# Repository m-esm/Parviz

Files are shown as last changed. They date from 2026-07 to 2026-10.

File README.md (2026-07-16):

<p align="center">
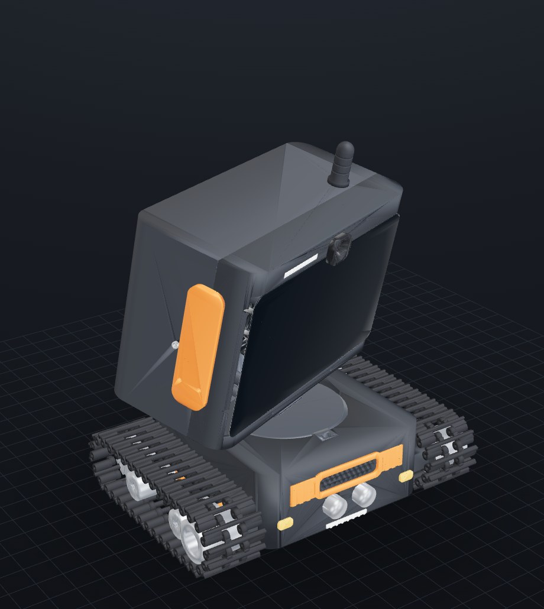
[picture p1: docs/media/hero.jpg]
Parviz, a 3D-printed tracked desk robot
  
</p>

<h1 align="center">Parviz</h1>

<p align="center"><b>Your desk AI.</b> A 3D-printed tank-tracked robot with a real face.</p>

<p align="center">
  <a href="https://m-esm.github.io/Parviz/viewer_glb.html"><b>&#9654; Spin the full assembly in your browser</b></a>
  &mdash; live 3D viewer with pan/tilt pose sliders, per-part toggles and the fit map
</p>

Parviz is a small tank-tracked robot that lives on a desk. A Raspberry Pi 5 drives
the official 7" touchscreen as an animated face, a Camera Module 3 sits behind the
forehead as an eye, and a pan/tilt neck lets the head look around. Two motor-driven
tank tracks let it drive. The whole thing is designed to print on a hobby FDM machine
(Bambu A1 class) and assemble with M2/M3 hardware plus a handful of bought bearings.

The mechanical design is parametric Python (`trimesh` + `manifold3d` + `shapely`), built
into a single `web/assembly.glb` you can spin in a browser. Every geometry change goes
through a headless render-and-inspect loop and a pairwise + pose-grid interference gate
before it counts as done. 39 parts, of which 10 are watertight printed structural parts;
the rest are cosmetics, bought hardware, and mechanism placeholders.

**Status:** design-complete and interference-gated in CAD, not yet printed or assembled.

## Designed to a concept, not vibes

<p align="center">
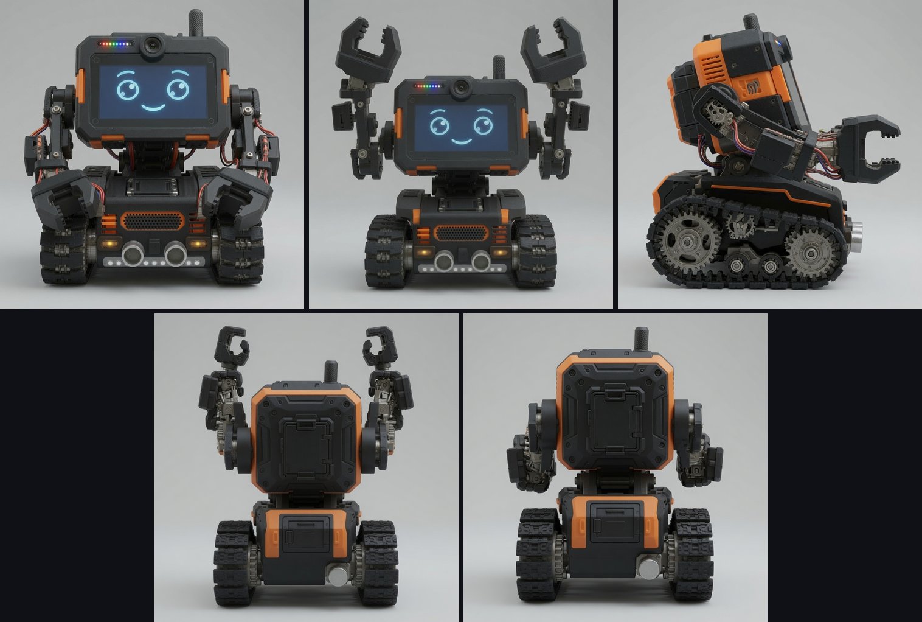
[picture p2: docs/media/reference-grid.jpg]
The five AI concept renders that define Parviz's look
  
</p>

The look came first. Five concept renders (`reference/design/`) fixed the design language:
a black-and-orange tracked body, a clean rounded tablet head with a cyan-eyed face, corner
lamps, a stubby antenna. The CAD was then built to match that silhouette around the real
hardware, not the other way round. The head is a rounded box (it started as an Echo-Show
wedge, since simplified) sized 205 mm wide to wrap the actual 192.96 mm touchscreen+Pi
module with room for the bezel.

## How it's engineered

**Tilt = self-locking worm drive.** The head pitches on a single-start involute worm meshing
a 12-tooth helical wheel, module 1.25, center distance 11.9 mm, lead angle ~8.1°. Single-start
plus printed-PLA friction (µ ≈ 0.3 vs the 0.129 self-lock threshold) means the head holds any
tilt angle with the motor de-energized: no idle current, no heat. The worm rides a 28BYJ-48
stepper (shaft +Y, right-angle to the axle); the wheel keys to a Ø5 hollow axle turning in two
695-2RS bearings pressed into the neck cheeks. Real tooth geometry is generated from first
principles (numpy involute → manifold twisted extrude) and verified to mesh cleanly (zero boolean interference)
at nominal center distance. See [docs/WORM.md](docs/WORM.md).

**Pan = direct D-hub on a captured-ball race.** A second 28BYJ-48 sits offset in the base so its
double-D shaft lands exactly on the pan axis and keys straight into a D-bore hub under the
platform: no reduction, no coupler fighting the offset. The top-heavy head rides a lazy-Susan
race of 18 loose 6 mm airsoft BBs on an Ø80 circle, captured between the platform's grooved
underside and the `pan_race` ring. A balanced vertical axis has no gravity torque to hold, so no
worm needed here. Software clamps pan to ±88° so the Pi power service loop never over-winds.

**Tracks = positive-drive tank pods.** Each side runs 36 printed link pads on Ø1.75 filament-rod
hinge pins (72 pins, ~3.4 m of filament) around a stadium loop, driven by a 12-tooth sprocket at
the rear and tensioned by an F688ZZ idler at the front. Positive tooth engagement beats a friction
belt that would slip when the head pans hard. One TT gearmotor per pod, skid/differential steer off
a single MX1588 H-bridge. Track geometry is adapted from the Thingiverse tank-track reference.

**Verification gates.** Nothing ships on a "looks right" render. `make check` runs pairwise
boolean interference across all parts (whitelist-aware for intended contacts); `make check-sweep`
re-runs it across the full pan × tilt pose grid so a joint that only clashes at −30° tilt gets
caught. An 18-step insertion/torque-path audit confirmed a complete assembly order exists with every
screw reachable at some point in the sequence (see below). Cable routing was re-verified segment by
segment with swept-conduit clearance probes after the head geometry moved.

## Gallery

<p align="center">
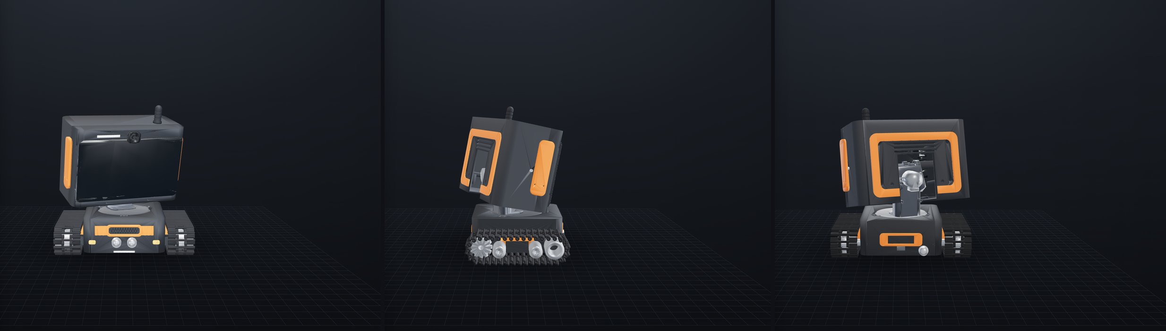
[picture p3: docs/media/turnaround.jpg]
Parviz front, side, and back
  
</p>

<p align="center">
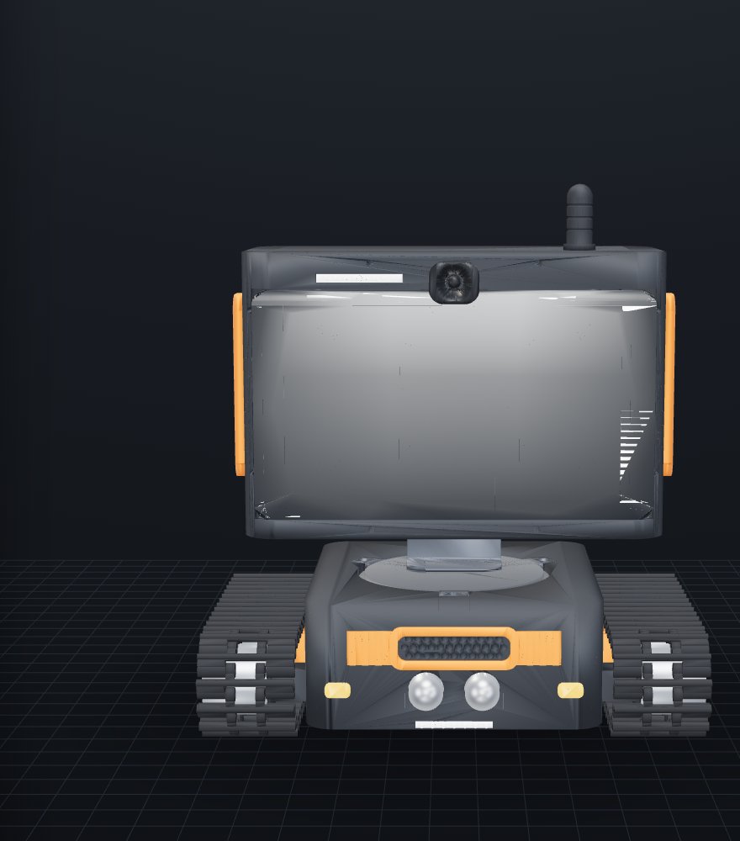
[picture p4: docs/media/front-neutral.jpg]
Parviz front, neutral pose
  
</p>

<p align="center">
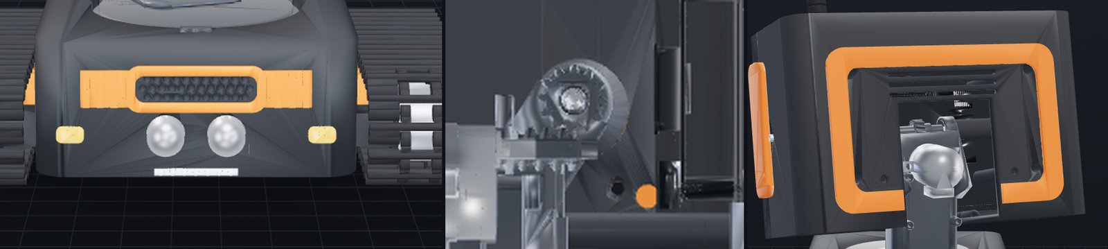
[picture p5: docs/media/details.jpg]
Fascia, worm mesh, and rear service door closeups
  
</p>

<p align="center">
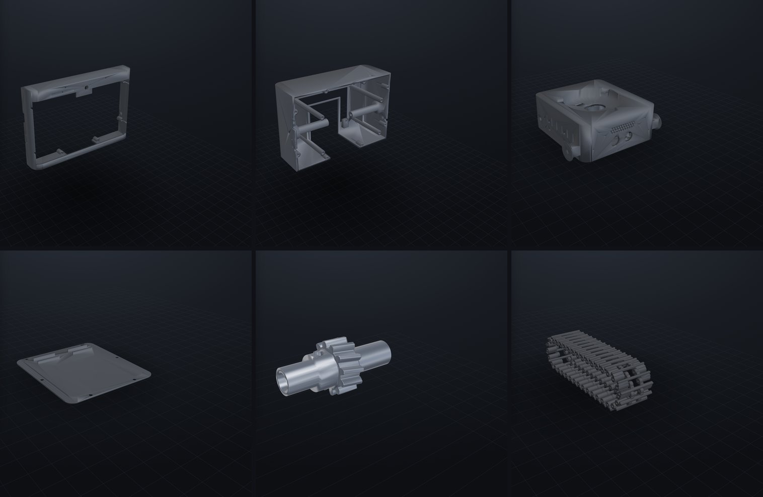
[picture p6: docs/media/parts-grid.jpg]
Six of the printed parts
  
</p>

## Build it

The loop, on every geometry change:

```bash
make install     # trimesh toolchain + headless Chromium (first time only)
make build       # python3 src/build.py -> web/assembly.glb
make viewer      # http://localhost:8770/viewer_glb.html (live-reloads on rebuild)
make shot        # headless renders -> .claude/renders/ (viewer must be running)
make check       # pairwise interference gate on the current assembly
make check-sweep # interference gate across the pan x tilt pose grid
make jointcheck  # declared mating geometry, fasteners, access, and assembly paths
make gate-tests  # prove the joint gates reject deliberately broken fixtures
```

`EXPORT=1 python3 src/build.py` writes the per-part STLs under `stl/{base,neck,head}/`.

Before producing print files, run `make assembly-release`. It regenerates the geometry,
runs the invariant, joint-contract, wall, static/swept interference, and fit gates in a
fixed order, rebuilds the printable files, headless-slices every Bambu plate, and renders
the docs. The explicit ordering prevents a parallel Make invocation from checking stale
STLs or a GLB while another target is rewriting it. Joint declarations and maintenance
rules live in [docs/JOINTS.md](docs/JOINTS.md); the machine-readable result is written to
`web/joint_report.json`.

**Assembly** is a verified 18-step order, from an insertion-path and torque-path audit, in
[docs/ASSEMBLY.md](docs/ASSEMBLY.md), including the full BOM cross-checked against on-hand
inventory. A few joints are reachable at exactly one point in the sequence (the worm-wheel grub
is bench-only; the screen standoffs must go in before the rear trim), so read the order
constraints before you start.

**Order now** (the long-lead / not-in-a-typical-bin parts):

- 2× F688ZZ flanged bearings (8×16×5): the track idler seats are modeled around them
- 1× TT gearmotor 1:120 to match the owned one (or commit to 2× N20 for a lower CoM)
- Official Raspberry Pi 27W USB-C PD supply (5.1V/5A): a 3A brick browns out under screen + camera + steppers
- Ø5 rod (~100 mm) for the tilt axle; a bag of 6 mm airsoft BBs (need 18) for the pan race
- 1 m narrow addressable LED strip (SK6805-2427 / WS2812-2020) for the forehead + front dots

**The one special tool:** a slim M3 driver with ~95 mm reach. The four screen-module standoff
screws drive down blind Ø7 channels ~88.5 mm long with ~0.75 mm around an M3 pan head. Pan/cheese
head only, a countersunk M3 (Ø6.0) will not enter the channel.

## Software

<p align="center">
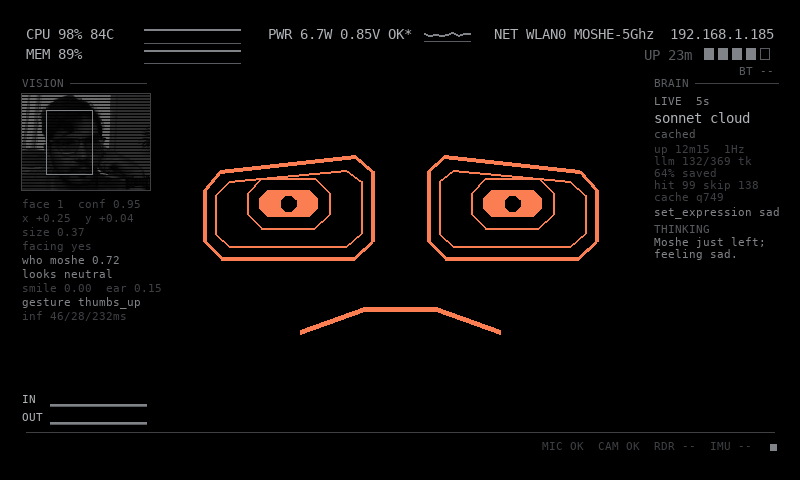
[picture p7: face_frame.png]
Live frame from Parviz's screen: orange face with HUD, vision panel, and brain telemetry
  
</p>

A live frame from the running robot (dumped over SSH with `kill -USR1`): the orange
face mid-conversation, CPU/power/net HUD, the camera vision panel, and the brain
column showing the cloud LLM tier ticking.

A working spike lives in `software/` (deployed to the Pi over rsync, key auth):

- **`face/`**: fullscreen 800×480 face renderer (pygame): navy background, cyan outlined eyes with
  offset pupils, arc brows, smile, idle blink. `set_expression()` API with neutral / happy / sad /
  surprised / sleepy / look_* states.
- **`motion/`**: 28BYJ-48 half-step driver (lgpio) with `PanStepper` (±88° hard clamp) and
  `TiltStepper` (±30°, 12:1 gear ratio, coils release after each move since the worm self-locks).
  Dry-run mode records coil writes without touching GPIO; 19/19 unit tests pass on any machine.
- **`camera/`**: one-frame capture check, Picamera2 with an `rpicam-still` fallback.

Runs on Raspberry Pi 5 (2GB), Raspberry Pi OS trixie, Camera Module 3 (imx708). See
[software/README.md](software/README.md) for deploy and smoke-test commands.

## Repo map

| Path | What |
|---|---|
| `src/build.py` | Source of truth. `PARAMS` block up top; builds chassis / tracks / pan / neck / head into the GLB |
| `src/serve.py` / `src/shoot.py` | Live viewer server / headless multi-angle renderer |
| `stl/{base,neck,head}/` | Per-part STLs written by `EXPORT=1` |
| `web/` | `viewer_glb.html` + committed `assembly.glb` (a fresh clone shows the robot) |
| `tools/gears/` | Worm/wheel tooth generator + mesh verifier (runs in a py3.10 venv) |
| `software/` | Face, stepper, and camera code for the Pi |
| `docs/` | [ASSEMBLY](docs/ASSEMBLY.md) (BOM + order), [JOINTS](docs/JOINTS.md) (machine-checked interface contracts), [WORM](docs/WORM.md), [PRINTABILITY](docs/PRINTABILITY.md), [FIXES](docs/FIXES.md) |
| `reference/` | Bought/borrowed CAD: touchscreen, camera, tank track, TT motor, display style |

## Design references & credits

Parviz stands on other people's models. All Thingiverse references are Creative Commons; keep the
attribution if you reuse them.

- **Tank track**: thing:3062624 by **advancedvb**, CC BY. Link pads, sprocket, and idler geometry.
- **Yellow TT motor**: thing:1079893 by **CCFIVE**, CC BY. Drive-motor placeholder.
- **Official 7" touchscreen reference model**: thing:1646255 by **clough42**, CC BY-SA. The
  combined screen+Pi (pins-out) mesh the whole robot is built around.
- **7" touchscreen case**: thing:1585924 by **luc_e**, CC BY-NC. Style/fit reference.
- **RPi Camera v2.1 model**: thing:1564160 by **jbeale**, CC BY. Camera placeholder (CM3 dims from
  the official Raspberry Pi mechanical drawing in `reference/rpi-camera-module-3/`).
- **Alexa-style smart display**: the wedge that inspired the original head shape
  (`reference/alexa-style-smart-display/`).
- **Concept renders**: the five AI-generated concept images in `reference/design/` that set the
  black-and-orange design language.
- Official Raspberry Pi CAD (touchscreen + Camera Module 3) from Raspberry Pi Ltd.

## License

The original work here (`src/`, `software/`, `docs/`, `tools/`, `web/`, `stl/`, CAD) is licensed
under **Apache-2.0** (see [LICENSE](LICENSE) and [NOTICE](NOTICE)).

The bundled `reference/` meshes are third-party and keep their own Creative Commons terms, listed
in [THIRD-PARTY-NOTICES.md](THIRD-PARTY-NOTICES.md). Two are restrictive: the touchscreen model is
**CC BY-SA** and the touchscreen case is **CC BY-NC**, so redistributing the repo as a whole is
non-commercial while those files are present. Remove them (and fetch at build time) if you need a
fully permissive tree.

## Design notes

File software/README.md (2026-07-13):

# desk-pi software

Parviz robot software. Awareness/LLM design intent: ../docs/AWARENESS.md.
Software spike for the tracked desk robot: face renderer, neck stepper
driver, camera check. Lives here in the repo and mirrored to `~/parviz-sw`
on the Pi (`ssh moshe@moshe-pi5-2gb.local`, key auth).

## Deploy

```sh
rsync -av --exclude __pycache__ software/ moshe@moshe-pi5-2gb.local:parviz-sw/
```

## Pieces

### face/face.py, fullscreen face (800x480, official 7" touchscreen)

Rigid-line robot face (2026-07-11 revision, per user): two rectangular
outlined eyes with square pupils, NO mouth, NO eyebrows, single color =
the body's safety orange (`src/geo.py COLORS["accent"]` = 232,116,34) on
black. Expressions come from lid height, top-corner tilt and pupil
position; every stroke is straight. Layout scales off the panel size
(eyes 224x192 centered at 240/560). Idle blink stays.
`FaceRenderer.set_expression(name)` API; expressions: neutral, happy, sad,
surprised, sleepy, look_left, look_right, look_up, look_down.

TOUCH: while a finger is on the panel the pupils track it and the eyes
widen slightly; lifting the finger blinks and returns to the current
expression. Handles both SDL FINGER* events (the DSI ft5x06 panel) and
mouse-drag (windowed dev).

Headless visual check (no compositor to screenshot through):
`kill -USR1 <pid>` makes the next frame land in `/tmp/face_frame.png`.

### face/parviz-face.service, boot service

The Pi boots to console (`sudo systemctl set-default multi-user.target`,
desktop disabled; revert with `graphical.target`) and systemd starts the
face fullscreen via KMS/DRM. SDL scans the DRM cards for a connected
connector, which is always the DSI panel (HDMI unplugged), so no device
index is pinned. DRM card numbers shuffle between boots; never hardcode
`/dev/dri/cardN`.

```sh
sudo cp face/parviz-face.service /etc/systemd/system/
sudo systemctl daemon-reload && sudo systemctl enable --now parviz-face
```

Needs pygame (check `python3 -c "import pygame"`; else
`pip3 install --user pygame`, no sudo).

```sh
# Over SSH, console owns the display (no desktop session):
SDL_VIDEODRIVER=kmsdrm python3 face/face.py --demo --seconds 10
# (face.py sets SDL_VIDEODRIVER=kmsdrm itself when no DISPLAY/WAYLAND_DISPLAY)

# If a Wayland desktop session owns the display, kmsdrm will fail
# ("Could not initialize KMSDRM", the compositor holds DRM master).
# Run inside the session instead:
WAYLAND_DISPLAY=wayland-0 XDG_RUNTIME_DIR=/run/user/1000 python3 face/face.py --seconds 10
# X11 desktop: DISPLAY=:0 python3 face/face.py --seconds 10

# Dev on a laptop:
python3 face/face.py --windowed --demo --seconds 10
```

`--seconds N` auto-exits (SSH smoke tests, nothing left running). Esc/q quits.

### motion/steppers.py, 28BYJ-48 half-step driver (lgpio)

`PanStepper` / `TiltStepper` on a shared `LimitedStepper`:

- **Pins are required, no defaults**, nothing is wired yet.
- **Pan hard clamp default ±88°** (constructor param `limit_deg`). The Pi
  power service loop in the neck must never over-wind; the ±90 mechanical
  target keeps a 2° software margin. `move_to`/`move_by` both clamp; relative
  moves cannot creep past.
- **Tilt clamp ±30°**, `gear_ratio=12` (single-start worm, 12T wheel). Worm
  self-locks, so coils release after every move (default `hold=False`).
- `dry_run=True` records coil writes in `.trace` instead of touching GPIO;
  lgpio imports lazily, so the module runs anywhere.

```sh
# Unit tests (any machine, no GPIO):
cd motion && python3 -m unittest test_steppers -v

# On the robot (once wired; BCM pin numbers for the ULN2003 IN1..IN4):
python3 -c "from steppers import PanStepper; PanStepper(pins=(17,18,27,22)).move_to(30)"
```

lgpio comes from the OS package `python3-lgpio` (should be present on
Raspberry Pi OS trixie; if not: `pip3 install --user lgpio`).

### camera/preview.py, one-frame capture check

Tries Picamera2, falls back to `rpicam-still`. Writes `/tmp/desk_pi_cam.jpg`
and prints backend + resolution (parses JPEG SOF, no PIL needed).

```sh
python3 camera/preview.py
# expect: OK: /tmp/desk_pi_cam.jpg (... KB) via picamera2, resolution 4608x2592
```

## Hardware verification status (2026-07-11)

**All three pieces verified on the Pi** (`moshe-pi5-2gb.local`, Pi 5 2GB,
Debian 13 trixie, kernel 6.18, Python 3.13.5; pygame 2.6.1 / lgpio /
picamera2 / numpy all present from the OS):

- `camera/preview.py`: full-res capture works,
  `OK: /tmp/desk_pi_cam.jpg (694 KB) via picamera2, resolution 4608x2592`
  (imx708 on CAM1). Frame pulled back and inspected, real image.
- `motion/test_steppers.py`: 19/19 pass on the Pi (no GPIO wired yet, so
  only dry-run coverage; live coil test waits on the ULN2003 wiring).
- `face/face.py --demo --seconds 12`: renders fullscreen on the 7" DSI
  panel (800x480); expression demo verified frame-by-frame via screenshots.
- **Boot service verified 2026-07-12**: `parviz-face.service` active after
  a real reboot, holding the DSI card via kmsdrm, ~10% of one core,
  system RAM 306 MB used (desktop disabled freed ~120 MB).
- **Touch verified end-to-end** with a virtual multitouch device
  (python3-evdev uinput, MT slots + `INPUT_PROP_DIRECT`): pupils track a
  synthetic drag-and-hold, release blinks. NOTE: a single-touch ABS
  uinput device does NOT work for this, SDL classifies it as a
  pointer and only the press comes through; emulate real MT.

Remote screenshots: desktop session up -> `grim -o DSI-2 out.png`;
console/service mode -> `kill -USR1 $(pgrep -fn face.py)` and fetch
`/tmp/face_frame.png` (the service renders into a DRM dumb buffer, there
is nothing for grim to grab).

## Next hardware step

Wire one 28BYJ-48 + ULN2003 to the Pi (pick 4 BCM pins, e.g. 17/18/27/22),
then run the first live coil test:
`python3 -c "from steppers import PanStepper; PanStepper(pins=(17,18,27,22)).move_to(30)"`.
After that: pin map into a `pins.py` (or config), and a supervisor that
ties face + camera + motion together.

## LLM on the Pi (measured 2026-07-12)

The Pi 5 2GB runs small LLMs fine, CPU-only. Runtime: **llama.cpp**,
built natively on the Pi (`~/llama.cpp/build/bin`, Cortex-A76 dotprod
kernels; `cmake -B build -DCMAKE_BUILD_TYPE=Release -DLLAMA_CURL=ON`).
Use **Q4_0** quants: llama.cpp runtime-repacks Q4_0 for the ARM dotprod
path, so it beats Q4_K_M on this CPU. Ollama was rejected: it wraps
llama.cpp anyway and its resident Go server wastes RAM the 2GB board
does not have. Models live in `~/models/`.

Measured with `llama-bench -t 4` (pp = prompt tokens/s, tg = generation
tokens/s), face service running throughout:

| model (Q4_0) | weights  | pp256 | tg64  | verdict |
|---|---|---|---|---|
| Qwen3-0.6B | 403 MiB  | 204 | 21.4  | daily driver |
| LFM2-1.2B | 661 MiB  |  94 | 11.0  | quality alt |
| Llama-3.2-1B | 730 MiB  |  84 |  9.0  | slower than LFM2, skip |
| Qwen3-1.7B | 1002 MiB |  55 |  6.5  | fits, sluggish; ceiling |

End-to-end serving check (Qwen3-0.6B, `llama-server -t 4 -c 2048`):
short persona reply in **0.94 s** wall clock cold; server RSS 937 MB;
face + server coexist with 1.17 GB still available. Qwen3 is a thinking
model, append `/no_think` to the system prompt for latency.

Serve command:

```sh
~/llama.cpp/build/bin/llama-server -m ~/models/Qwen3-0.6B-Q4_0.gguf \
    -t 4 -c 2048 --host 127.0.0.1 --port 8081
# OpenAI-compatible: POST localhost:8081/v1/chat/completions
```

Honest quality note: 0.6B-1.7B models handle persona lines, command
parsing and simple Q&A; they are not good conversationalists. For real
conversation quality the right architecture is a remote brain (API or a
bigger box) with the local model as the offline/latency fallback.
Budget rule: keep model + KV under ~1.2 GB so the face, camera and
supervisor never fight the OOM killer.

### llm/parviz-llm.service, local LLM chat (llama-server)

Persistent Tier-2 brain service (docs/AWARENESS.md): llama.cpp
`llama-server` + Qwen3-0.6B-Q4_0, enabled on boot next to the face.
**Chat UI: http://moshe-pi5-2gb.local:8081/** (LAN), API at
`/v1/chat/completions` (OpenAI-compatible). `MemoryMax=1400M` so a
runaway LLM gets killed before it OOMs the face. Qwen3 thinks by
default; add `/no_think` to the system prompt for snappy replies.
Verified 2026-07-12: service + face active together, 1.1 GB still free.

### brain/scenarios.py, simulated sensory input -> LLM behavior

The Tier-2 loop from docs/AWARENESS.md, runnable before any sensor
exists: full-suite sensor SNAPSHOTs (mics/camera/mmWave/IMU/vibration/
env/sonar/cliff/touch) render to a compact text digest; the system
prompt gives Parviz's behavior rules + a constrained action vocabulary
(do_nothing / set_expression / look_at / say / move / log / escalate);
10 scenarios (idle, person approaches, voice command, picked up, cliff
stop, loud noise, stuffy room, petting, escalation-worthy question,
late night) run against llama-server. Output shape is grammar-enforced
via response_format json_schema; results append to
`brain/results/<tag>.jsonl` with per-scenario `expect` verbs for the
upcoming behavior benchmark.

```sh
python3 brain/scenarios.py --host moshe-pi5-2gb.local:8081 --tag mytag
python3 brain/scenarios.py --scenario person_approaches --runs 5
python3 brain/scenarios.py --digest-only   # inspect digests, no LLM
```

Findings on Qwen3-0.6B (2026-07-12, results/ committed):
- raw prompt: right instincts, broken JSON shape; json_object grammar +
  thinking template = empty replies.
- schema-only: valid JSON but DEGENERATE (`look_at` twice for every
  scenario, no parameters). Grammar alone kills a 0.6B.
- schema + 2 few-shot examples + `chat_template_kwargs
  {"enable_thinking": false}`: parameterized sensible actions (~6-10 s
  per decision). Residual 0.6B failures, the benchmark targets: copies
  the few-shot pan_deg=45 verbatim (looks RIGHT at a LEFT sound), never
  chooses `escalate` or `say`, occasional gratuitous look_at when idle.

### brain/bench_report.py, side-by-side behavior report

Reads `results/*.jsonl`, scores every run (pass = all expected verbs, no
forbidden; partial = some expected; fail = forbidden/none/broken JSON)
and writes self-contained `report.html`: score matrix, then per scenario
the exact digest + every model's actions/reason/latency side by side.
`python3 bench_report.py qwen3-0.6b llama3.2-1b lfm2-1.2b qwen3-1.7b`.
First 4-model run (2026-07-12): qwen3-0.6b 6P/3~/2F, lfm2-1.2b 5P/3~/3F,
qwen3-1.7b 3P/3~/5F (over-passive do_nothing bias; answers the visual
question itself instead of escalating), llama3.2-1b 3P/0~/8F (says
something for nearly every scenario). Deterministic verb scoring is
crude and favors the few-shot pattern; an LLM-judge pass is the next
benchmarking step.

Prompt-format ablation (2026-07-12, user hypothesis "maybe the prompt is
wrong for these models" -- partly confirmed): `--prompt v2` = EVENT-first
digest with explicit side hints ("from LEFT (pan negative)"), compact
decision-guide system prompt, 4 diverse few-shots (incl. escalate + say).
Results: v2 improved every metric it touched -- qwen3-0.6b 2F->1F and the
left/right pan sign FIXED (+45 -> -45; v1's sign error was pure prompt
anchoring), qwen3-1.7b 3P->5P. But NO model ever chooses `escalate`, even
with an explicit escalate example: tiny models cannot tell "answerable
from digest" from "needs outside capability". That is a capability gap,
not a prompt gap, and the headline metric for model selection.

Face UX v3 (2026-07-12): micro-saccades + breathing (never freezes),
1.6 s boot curtain reveal with typed "PARVIZ // BOOT", DIM-orange HUD
(corner brackets, "PARVIZ // <EXPRESSION>" + blinking cursor, breathing
heartbeat pip), chamfered touch ripples. Same 10% of one core. SIGUSR1
is ignored until the renderer's handler is up (a dump request during
pygame init used to KILL the process, default USR1 disposition).

Demo mode (2026-07-12): `--demo` now loops 11 scripted SCENES on timed
intervals (idle scan, person detected -> track -> hello, wake word ->
listening, thinking, speaking, escalate "ASKING BIG BRAIN", cliff alert
flash, petted, low power, sleep with shut-bar eyes + ZZZ, wake), each
driving expression + the HUD status line ("SCENE // STATE" with animated
dots). DEMO_SCENES/DemoDirector in face.py; the renderer's `status`
field is the same hook the brain loop will use later. Run on the Pi:
`sudo systemctl stop parviz-face && cd parviz-sw &&
SDL_VIDEODRIVER=kmsdrm python3 face/face.py --demo --seconds 45;
sudo systemctl start parviz-face`

Face v4 (2026-07-12, user feedback rounds): eyes = TWO THIN OUTLINES
(4px outer + 2px inset echo, GAP 11; the bold filled ring is gone) and
more expressive: bottom-lid `squint` (happy is a squint, not a droop)
and `pupil` dilation per expression (surprised = pinpoint, happy/touch
= dilated). Eyes moved high (cy 0.365*H); a rigid 3-segment MOUTH is
back by user request (smile/frown polyline; chamfered-O when `open`,
surprise/speaking) at 0.72*H. Bottom TELEMETRY bar refreshed every 5 s:
CPU temp + NET (wlan/eth operstate) + PWR AC real today, MIC/CAM/RDR
show `--` until the hardware is wired (AWARENESS.md suite). All still
one hue, straight strokes, ~10% CPU.

Face v5 (2026-07-12): PUPILS rebuilt as iris ring + filled octagon core
+ BG glint notch, with hippus (dilation twitches on saccades). HUD got
its own cool palette (user: ORANGE IS FACE-ONLY now): slate text, cyan
graphs/accents, green/red states. Corner blocks: SYS top-left (CPU temp
+ load + mem, 48-sample cyan temp sparkline @2 s), NET top-right (dev,
IP, uptime, 5-segment wifi signal bar from /proc/net/wireless), status
line bottom-left (cyan cursor), sensor slots + green PWR AC + cyan
heartbeat pip bottom-right. Telemetry class samples procfs/sysfs fast
items @2 s, slow @30 s, degrades to '--'. TOUCH: per-eye gaze, each eye
aims at the finger independently (renderer eases per eye), so a poke
BETWEEN THE EYES goes cross-eyed + opens a silly o-mouth (user todo).

Face v6 (2026-07-12, user rounds): HUD went LIGHT-GRAY monochrome
(orange = face only; three grays, red reserved for alerts), MEM sparkline
joined CPU (fixed 0-100% scale, labels left), dedicated PWR block top-
center: real PMIC numbers via `vcgencmd pmic_read_adc` (sum of rail V*A
= board watts, ~2.4 W idle, + core V + throttle state; OK* = past
undervolt since boot) with a watts sparkline; NET gained the SSID (`iw
dev wlan0 info`, iwgetid is not on trixie). LLM DECISIONS show subtly
bottom-center: the brain writes {"actions":[...],"reason":...} to
/tmp/parviz_decision.json, the face polls mtime every 2 s and shows
"verbs // reason" while <120 s fresh (first face<->brain IPC). Pupil
GLINT rides the gaze (dot sits where the eye looks). Touch between the
eyes = DERP per user ref image: near eye stares at the finger, other
rolls up-out. BG is true (0,0,0); the residual glow is IPS backlight,
so the service dims it to 120/255 at start (ExecStartPre tee -- sh does
NOT glob redirection targets, tee args do). Settled CPU ~6% of one core.

Face v7 (2026-07-12): EMOTIONS +concerned/angry/sick (angry = the
positive-tilt V + pinpoint pupils + frown; sick = droopy + queasy
half-open mouth). PUPIL ANATOMY corrected per user: the orange octagon
is the fixed-size IRIS, the black dot inside is the PUPIL, it DILATES
(surprised ~11 px, happy ~25 px) and rides the gaze. DEMO now covers
every case: all 12 expressions + 4 gaze directions + talking mouth-flap
(SPEAKING modulates `open` per frame) + a BOOP scene that injects a
synthetic between-the-eyes touch (derp + ripple) + INTRUDER/SAD scenes.
CAMERA PREVIEW: 96x72 live window right-edge center (picamera2 lores
160x120 BGR888 at ~6 fps; fails soft to CAM --). Costs +30 MB RSS and
~6% of one core. NOTE: the face process now OWNS the camera; when the
perception process arrives it takes ownership and the preview should
consume ITS frames instead. Brain schema updated with the new emotion
names (scenarios.py enum + prompts).

### perception/perceive.py, YuNet vision daemon (2026-07-12)

Tier-1 vision per the user's benchmark research: OpenCV FaceDetectorYN
(YuNet 2023mar ONNX, 232 KB, in models/) on picamera2 640x480 -> 320x240,
15 Hz loop. SOLE camera owner (the face's CamPreview now READS its
/dev/shm frames instead of opening picamera2). Publishes atomically:
- /dev/shm/parviz_vision.json: interaction state (person_present, conf,
  cx/cy robot-frame normalized, size, facing_camera heuristic, pan/tilt
  suggestion, raw det box, fps, infer_ms)
- /dev/shm/parviz_preview.jpg: 160x120 @3 Hz for the face CAM window
Measured on-device: ~16 ms inference, 189 MB RSS, live detection of a
real face at 0.95 conf. Detection rate 1 Hz per user (15 Hz = 77% of a
core, 1 Hz = ~10%), `--hz` overrides. The face CAM window is a bottom-
left GHOST FEED (144x108, grayscale, alpha 110 into the black, scanlines
every 3 px) with the detection box + raw numbers beside it. `--bench N` prints the
research CSV; `--image f.jpg` one-shot test. parviz-perception.service
(MemoryMax=400M) enabled on boot.

Face integration: idle eyes FOLLOW the detected person (VisionGaze,
neutral expression only; touch and brain expressions win), CAM window
draws the raw detection box + faint raw numbers (HUD_FAINT 11 px, user:
subtle), CAM slot shows OK from frame freshness. DEMO TOGGLE: triple-tap
the screen within 1 s toggles demo mode at runtime, OFF by default.

Pipeline stage 2 (2026-07-12, user's diagram): Camera -> YuNet -> CROP+
ALIGN (rotate on YuNet eye line, 1.7x box margin, 256x256) -> MediaPipe
FACE LANDMARKER -> behavior. No mediapipe python wheel exists for
cp313/aarch64, so the .task bundle's face_landmarks_detector.tflite
(478 pts, in models/) runs directly via ai-edge-litert (pip, installed
--user on the Pi); its confidence head is a LOGIT (sigmoid it). The
bundled blendshapes model needs mediapipe's private 146-index subset, so
expression SIGNALS are geometric from canonical facemesh indices: EAR
(eyes_closed <0.16), mouth_open (13-14 gap / face height), smile (mouth
width/jaw width + corner lift), brow_gap -> visible_expression label
(neutral/happy/surprised/eyes_closed; visible, not felt). Measured live:
landmarker 26 ms on top of YuNet 16 ms, still 1 Hz. Face BEHAVIOR: smile
mirror -- person smiles (smile>0.5) -> Parviz goes happy, reverts when
the smile goes (only if vision set it; touch/demo/brain win). Raw line
under the cam feed now shows the label + smile score + lmk ms. Verified
end-to-end on a live smile at the desk.

### brain/brain.py + parviz-brain.service, THE LOOP IS CLOSED (2026-07-12)

The LLM is now the ONLY source of truth for behavior (user directive).
brain.py ticks every 15 s (inference is 7-15 s; faster ticks ran the
fanless Pi to 85C throttle): builds a digest of EVERYTHING (all vision
features incl. raw signals + confidences + timings, cpu/mem/temp, time,
an event ring of person arrived/left + expression changes + its own past
actions), asks the local Qwen (v2 prompt/schema imported from
scenarios.py), writes /tmp/parviz_decision.json, journals to
brain/journal.log. The face EXECUTES decisions (set_expression /
look_at -> eye gaze / say -> status line for 6 s) and the smile-mirror +
person-following reflexes were REMOVED - the LLM sees those signals and
decides. HEARTBEAT CONTRACT: decision-file mtime stale >45 s (brain or
LLM down) -> the face puts itself to sleep; verified by killing both
services (face went sleepy alone) and recovery through llama-server
restarts (rides the 500/503s). Eyes sized down (188x158) so the HUD
reads clearly. THERMAL NOTE: sustained brain ticking holds the SoC near
80-85C on the bare board - a heatsink/active cooler belongs on the buy
list before longer runs.

HUD layout v2 (2026-07-12, user: use the sides, label provenance): the
side bands are now PANELS with hairline headers -- left "VISION" (ghost
cam feed + detection box + every model value stacked: faces/conf, x/y,
size, facing, looks+smile+ear, model timings), right "BRAIN" (LIVE/STALE
+ decision age, the LLM's action list, reason word-wrapped with
ellipsis). Top row stays system (SYS/PWR/NET), bottom stays robot
(status line, sensor slots, pip). The old scattered decision line +
bottom-left cam block are gone; cam is 128x96 to fit the panel column.
Self-reviewed via frame dumps; fixed text/eye clipping and truncation.

Prompt v3 (2026-07-12, user: "LLM doesn't react to emotion/position"):
audit found the model never used look_at with real coordinates, never
mirrored emotion, and ignored person-left/late-night/hot-cpu. v3 fixes
it with explicit priority rules (person present -> BOTH look_at using
the digest's head-aim numbers AND set_expression matching their visible
emotion; person left -> center + sad; late night -> sleepy; cpu >80C ->
log) and 4 few-shots in the LIVE digest format demonstrating each. The
digest's EVENT line now leads with the current person state (tiny
models act on the top line). Verified live: look_at pan -11.6 vs actual
-11.8 (real numbers, not few-shot copies) and the journal shows "They
are smiling at me; smile back and keep eye contact" -- the emotion
mirror through the LLM. Face executor gain fixed: +-35 deg = full eye
deflection (/88 made tracking invisible). KNOWN TRADEOFF: LLM-only gaze
tracking has the tick latency (10-15 s); smooth fast tracking would
need a reflex, which the user explicitly removed in favor of LLM truth.

Gestures + tracking bypass + latency (2026-07-12, user round):
- TRACKING BYPASS: person-following eyes are a fast reflex again;
  look_at REMOVED from the LLM vocabulary (v3 prompt states "you do NOT
  control gaze"), executor ignores stray look_at. LLM keeps expressions,
  say, log, escalate, move.
- GESTURES: hands.py runs the gesture_recognizer.task internals via
  LiteRT (no mediapipe wheel): palm detector (192x192 SSD, anchors
  generated + decoded by hand), rotated crop, 21-pt hand landmarks,
  GEOMETRIC classification (open_palm/fist/thumbs_up/thumbs_down/
  pointing/victory). Validated 3/3 on mediapipe reference images; ~85 ms
  per tick when a person is present. Gesture flows into the digest +
  VISION panel; v3 rule 1 maps gestures to reactions (wave -> happy +
  greeting). Verified live: "Person is neutral; showing victory."
- LATENCY: cache_prompt=True keeps the ~1400-token system+few-shot
  prefix in llama-server KV cache -- cycles dropped 10-25 s to ~6-8 s
  (prompt ~2.5 s + gen ~4 s); reasons capped at 10 words; the BRAIN
  panel now shows "cycle X.Xs (prompt+gen)" prominently.
- FACE: a grand rigid-line MUSTACHE (user: much bigger), bottom-band
  hairline separator, panel line spacing 14 px.

Expressiveness + optimization pass (2026-07-12): mustache removed (user).
Why the face felt non-expressive: vision under-labeled (smile>0.5 was a
high bar) and the fixed 15 s tick outlived the user's expressions. Fixes:
smile threshold 0.4 + more sensitive formula, new "sad" label (corner
droop), perception rate ADAPTIVE (2 Hz person present / 0.5 Hz empty
desk), and the brain is EVENT-DRIVEN: polls vision every 1 s and ticks
IMMEDIATELY on presence/expression/gesture change, 20 s heartbeat
otherwise, 4 s cooldown floor (thermals). max_tokens 120. Verified live:
victory sign -> "Person is showing victory; surprised" -> face went
SURPRISED within one ~9 s cycle. Sustained load still parks the bare
SoC at ~84 C: the active cooler is now the single biggest optimization
available for this app.

Cycle/OS optimization audit (2026-07-12, user): found REAL issues --
(1) ACTIVE THERMAL THROTTLE: throttled=0xf0006, ARM pinned at 1.5 of
2.4 GHz; every stage runs ~40% slow. Software cannot fix this: BUY THE
ACTIVE COOLER. (2) Memory pressure: 470 MB into zram swap; fixed with
llama-server --flash-attn + q8_0 KV cache and service restarts -- used
1670->1040 MB, zram 470->69 MB, mem 82->51%. (3) Perception 44% of a
core: hand pipeline now runs every OTHER tick (result carried so the
brain's event key doesn't flap) -> 24%. (4) Load avg 5.4 on 4 cores:
reduced by 2+3. DEMO MODE REMOVED entirely per user (DemoDirector,
scenes, --demo, triple-tap; the brain is the only behavior source now).
BRAIN panel cycle line + action lines truncate to panel width (text ran
off-screen), panel margins widened. NOTE the demo removal initially
deleted Telemetry/CamPreview/VisionGaze with it (face crash-looped;
restored from git HEAD) -- deletion by text-range needs the range
checked against class boundaries.

Stress tint + polish (2026-07-12): the FACE COLOR is now a health
indicator -- orange drifts toward RED with the WORST of cpu temp
(60-85C), load (50-100%) and mem (60-95%), eased at 1.2/s so it
breathes. Verified live: at 85C throttle the whole face runs deep red.
Executor de-dupes contradictory duplicate set_expression actions in one
decision (last wins). HUD margins equalized: content sits 26 px from
ALL four edges (top/bottom rows were 6 px tighter than the sides).

No-brain mode (2026-07-12, user): when the decision file goes stale the
face enters a proper NO-BRAIN state instead of plain sleepy: new
face-internal "dozing" expression (near-shut lids with a slow 0.7 Hz
breathing drift, the LLM cannot select it), animated status "BRAIN
STARTING..." (never had a decision since face start; LLM warming) vs
"BRAIN OFFLINE..." (had one, lost it), and the BRAIN panel shows
WARMING UP vs OFFLINE -> dozing (red). Wakes to neutral the moment
decisions resume. Verified by killing brain+llm (dozed at 55 s) and
recovery (caught the user waving within one cycle of restart).

Thermal cooldown mode (2026-07-12, user): a circuit breaker across all
three daemons. brain.py and perceive.py watch the SoC temp (enter >=85C =
the firmware HARD-throttle onset per raspberrypi.com docs; RAISED from 80C
on 2026-07-13, user "it goes to cooling too often" -- the passive-heatsink
board sits at 80-85C under normal brain load so the old soft-throttle
threshold tripped constantly; resume <=80C hysteresis, was 70C which took
minutes to reach off-load; PARVIZ_COOL_ENTER/EXIT env overrides for
testing): while hot the brain stops ticking the LLM (writes
/dev/shm/parviz_cooling as the state marker) and perception skips all
inference (publishes {"cooling":true}). The face sees the marker and
shows the cooldown state instead of no-brain dozing: face-internal
"hot" expression (droopy lids, panting mouth oscillation), pale-blue
SWEAT DROPS sliding from the brow line, "COOLING DOWN <temp>C..."
status, amber "COOLING (paused)" in the BRAIN panel. Verified via the
marker (visuals) and a lowered-threshold live run (real trigger +
resume). At the 85/80 thresholds the breaker fires only when the firmware
is actually hard-throttling; normal 80-85C brain load runs uninterrupted.
The active cooler (task #1) would eliminate even those trips.

Eyes = camera (2026-07-12, user): when vision is OFF the face closes
its eyes. VisionGaze tracks `online` (fresh vision json AND not
cooling); a blind factor eases the lids fully shut when offline and
reopens on frames (waking-eyes effect at perception boot). VISION panel
states: "OFFLINE, eyes shut" (amber) vs "paused: cooling". Composes
with cooldown: while cooling, vision is paused, so Parviz sweats WITH
its eyes closed.

## AirPods audio (paired 2026-07-12)

"Mohsen's AirPods" (14:98:77:F0:ED:40) are paired/trusted -> auto-
reconnect. Default sink: bluez_output.14_98_77_F0_ED_40.1. Stack:
pipewire+wireplumber user services with `loginctl enable-linger moshe`
(survive reboot/no-SSH), `libspa-0.2-bluetooth` (A2DP; NOT installed by
default), pulseaudio-utils for pactl.

THE lesson: on a busy-RF desk, BlueZ's default dual-mode discovery
NEVER saw the AirPods (btmon showed zero packets from them during scans)
while raw classic inquiry (`hcitool scan`) saw them fine. Fix =
`ControllerMode = bredr` in /etc/bluetooth/main.conf + restart: classic-
only discovery found them in 18 s. NOTE this disables BLE on the Pi
(fine: sensors go through the Arduino). bluetoothd also runs with -E
(experimental drop-in) from debugging; harmless, can be removed. Pairing
UX: hold the case button (lid open) ~10 s PAST the green/amber status
blink until the light PULSES WHITE; iPhone Bluetooth must be OFF or iOS
re-captures them. audio/pair_airpods.sh re-pairs after a factory reset.

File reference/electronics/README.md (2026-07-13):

# reference/electronics

Downloaded reference CAD for the electronic parts in the build (see
[docs/ELECTRONICS.md](../../docs/ELECTRONICS.md) for the full parts table). These
are for dimension-checking the placeholders in `src/motors.py`/`src/chassis.py`,
not for printing. Verify against the datasheet before trusting any fit.

| Dir | Thing | License | Note |
|---|---|---|---|
| `stepper-28byj48-4919536/` | thing:4919536 | CC BY | 28BYJ-48 stepper: STL + F3D + IGES |
| `tt-motor-1079893/` | thing:1079893 | CC BY | yellow TT gearmotor: STL + STEP (69.5x22.4x29.9) |
| `hcsr04-dvemac-3653635/` | thing:3653635 | CC BY | HC-SR04: STL + SLDPRT + F3D + 3MF (45.2x18.5x26.5) |
| `hcsr04-markbenson-122136/` | thing:122136 | CC BY-NC | HC-SR04: OpenSCAD source |
| `rpi-cam3-wide-mockup-6939162/` | thing:6939162 | CC BY-SA | Camera Module 3 Wide mockup STL (25.0x23.9 board) |
| `arduino-uno-r3-346338/` | thing:346338 | CC BY-SA | Arduino Uno R3: OBJ (DesignSpark .rsdoc dropped, unusable format) |

NOT downloaded: ULN2003 driver board (thing:3781347, CC0) -- Chrome silently
swallows that thing's download; grab it by hand if the placeholder ever needs
checking. The driver board is a plain ~35x32 mm rectangle.

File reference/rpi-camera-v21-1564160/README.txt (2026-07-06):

Raspberry Pi Camera v2.1 Model by jbeale on Thingiverse: https://www.thingiverse.com/thing:1564160

Summary:
Mechanical model of Raspberry Pi Camera v2.1 with PCB, camera module and flex connector to assist in making housings or accessories for the camera. Believed accurate but I wouldn't rely on it without confirming yourself. OpenSCAD source file included. I used this model to create this lens adaptor http://www.thingiverse.com/thing:1565909 which does fit well on the v2.1 board.

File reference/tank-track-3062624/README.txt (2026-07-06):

Tank track by advancedvb on Thingiverse: https://www.thingiverse.com/thing:3062624

Summary:
The tracks are finally moving!Since I like the improving tank designs from timmiclark a lot, I had to do something with this.The flat track layout from MR4, is more handy (in case of rotational platform on top), I'm going for this design. Since the MR6 tracks seems to be improved version, I'll use this track interface.I did change the tracks, although they should still match the gearing from MR6:Changed some drafts, so no brim/support is requiredAdded both a 2.85 (&amp; 1.75 experimental)Changed the height of the outside of the track. Outer dimension is now 50 mm. I think this will improve the track movement, when the outside is closer to the same height of the pivot points.There are 2 options:Using 2 electric motors for one track:36x tracks + filament rods2x motor frames4x driving wheels 2x motors.Using 1 electric motor for one track:36x tracks2x motor frames2x driving wheels 2x driven wheels2x fake motor parts1x motors.2x flanged bearingAdjustments needed:Bore hole in motor frame, where you want to have the wires coming out.I remembered, drilling all track holes for better fit.MR4 compatibility:It's also possible to reuse the MR4 body parts.So in this case the basic difference with MR4 tank: improved tracks.

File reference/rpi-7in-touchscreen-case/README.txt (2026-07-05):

Raspberry Pi 7 Inch Touchscreen display case by luc_e on Thingiverse: https://www.thingiverse.com/thing:1585924

Summary:
Easy to print solid Raspberry Pi 2 or 3, Official 7 inch touchscreen case. I wanted to keep the black bezel look of the screen and not making it bigger. You will need 4 M3x6 or 8 screws to secure the back cover. There is room inside for the power cables.I will use this as a kiosk display and NAS for my Kodi player I have cut out some areas at the back where I can add velcro strips to mount a 2.5 inch HDD.Enjoy and show off your builds and mods.Update 290516: Added 2cm Velcro lid and lid without HDD support.Update 310516: Added new case with little door access to the SD card. Still need small pliers or pincet but it's easier than unscrewing the back lid.Update 150317: Added split STL for front to enable print on small print beds.Update 010118: Added split STL for case Left and Right to enable print on small print bedsUpdate 240418: Added the 123Design source files

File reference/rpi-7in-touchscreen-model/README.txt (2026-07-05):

Official Raspberry Pi 7" Touch Screen Reference Model by clough42 on Thingiverse: https://www.thingiverse.com/thing:1646255

Summary:
This thing is a reference model of the Official Raspberry Pi 7" Touch Screen Display.The parts modeled in this thing are available here:Official Raspberry Pi 7" Touchscreen Display:  http://amzn.to/28UEiWPRaspberry Pi 3 (Canakit with power supply):  http://amzn.to/28WNYmF32GB SanDisk Ultra Micro SD card:  http://amzn.to/28WO7GRThree versions of the model are provided:Bare LCD screenWith Raspberry Pi, mounted pins-outWith Raspberry Pi, mounted pins-inAll three are provided in STL, IGES and STEP format.I don't recommend printing this.  It's intended as a reference model for designing your own parts to fit.When you click on these links and make a purchase, it can result in commissions from Amazon that help support my work.

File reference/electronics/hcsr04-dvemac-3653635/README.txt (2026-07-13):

HC-SR04 Ultrasonic sensor by dvemac on Thingiverse: https://www.thingiverse.com/thing:3653635

Summary:
HC-SR04 Ultrasonic arduino sensor outline file for use in design work.

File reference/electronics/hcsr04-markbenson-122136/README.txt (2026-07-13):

Ultrasonic sensor HC-SR04 by markbenson on Thingiverse: https://www.thingiverse.com/thing:122136

Summary:
An scad model of the cheap ultrasonic sensor/range finder from ebay. Part number HC-SR04.  This is intended to help model a maze mouse that uses these sensors. The model is based on limited information (basic dimensions) and a photo. Hopefully it is about right.  Updated the model with better dimensions from a more comprehensive datasheet. Should be correct now.

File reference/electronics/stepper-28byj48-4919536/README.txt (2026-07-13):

Stepper Motor 28BYJ-48 Model by MajicDesigns on Thingiverse: https://www.thingiverse.com/thing:4919536

Summary:
A model of the 28BYJ-48 Stepper motor.Includes Fusion360 model, Iges file and STL.

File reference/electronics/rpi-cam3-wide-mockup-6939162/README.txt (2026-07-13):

Raspberry Pi Camera Module 3 Wide - Mockup by bestrafender on Thingiverse: https://www.thingiverse.com/thing:6939162

Summary:
This is a mockup of the Raspberry Pi Camera Module version 3 Wide

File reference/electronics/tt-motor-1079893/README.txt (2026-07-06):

yellow TT motor by CCFIVE on Thingiverse: https://www.thingiverse.com/thing:1079893

Summary:
tt motor

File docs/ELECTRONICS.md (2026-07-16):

# Electronics

Every electronic component in the Parviz build: what it does, whether it is owned,
and where to download a reference CAD model. Status comes from the 2026-07-13
inventory re-audit plus the **2026-07-14 order batch** (Tray 1, ordered NOT yet
delivered; see ASSEMBLY.md for the full BOM including mechanical hardware).

**2026-07-14 order batch (changes the plan):** Pi 5 **8GB** (lifts the 2GB RAM
ceiling), 2x **Sense HAT Rev2** (covers the IMU + env-sensor buys, adds
color/light + LED matrix + joystick), **AI Camera IMX500** (resolves the
AWARENESS.md "AI camera" open decision), 2x **Joy-IT RPI5-HEATSINK5** coolers
(bigger than the verified head keep-out -- see its row), a 30x10 5V fan, an
A4988 bipolar stepper driver and 6x N20 gearmotors (no design use yet, options
noted below). Everything in this batch is VERIFY_ON_ARRIVAL for dims.

Reference models matter because the CAD placeholders in `src/motors.py` and the
sensor/board placeholders in `src/chassis.py` were dimensioned from datasheets;
a downloaded mesh is the fastest way to sanity-check a placeholder against the real
part. **Verify any downloaded mesh against the datasheet before trusting fits** --
some Thingiverse "models" are low-poly illustrations, not mechanical CAD.

**Integrated into the assembly (2026-07-13):** the downloaded meshes for the
28BYJ-48, TT gearmotor, HC-SR04, Arduino Uno, and Camera Module 3 now REPLACE
their box/cylinder placeholders in `web/assembly.glb`, so the viewer shows the
real part geometry. `src/refparts.py` poses each real mesh onto the placeholder's
oriented bounding box by a 24-orientation best-fit, so it lands at the exact
placeholder location and orientation. **Exception (2026-07-16): the 28BYJ-48 is
registered deterministically instead** -- the OBB best-fit is blind to its
eccentric shaft and parked every real stepper ~15 mm off its gear axis, so
refparts recovers the placeholder's exact pose (Kabsch over the vertex
correspondence) and applies a fixed measured native-to-local transform; the
shaft now lands on the pan/tilt/antenna gear axes within the mesh's own 0.125 mm
eccentricity slop (guarded by `tests/test_refparts_28byj.py`). The same pass
deleted the placeholder's phantom 9 mm gearbox tier (see CLAUDE.md) so the real
motor's shaft actually reaches its gears. They are bought parts, never printed, and
skipped by the boolean interference/fit gates (like the non-watertight screen
mesh). `PLACEHOLDER_PARTS=1 make build` restores the analytic placeholders and
their full gate coverage. The ULN2003 has no downloaded mesh (see below), so it
keeps its placeholder.

## Compute + head module

| Component | Role | Status | Reference model |
|---|---|---|---|
| Raspberry Pi 5 (2GB) | Brain: face render, perception, local LLM, voice | OWNED (on the bench, `moshe-pi5-2gb.local`) | No board model on Thingiverse; official STEP at [rpi products page](https://www.raspberrypi.com/products/raspberry-pi-5/) -- and the repo already carries the combined screen+Pi mesh in `reference/rpi-7in-touchscreen-model/` |
| Raspberry Pi 5 **8GB** | Brain upgrade: lifts the 2GB RAM ceiling (AWARENESS.md budget: 1.7B-class ambient LLM + bigger ASR fit NEXT TO the face now) | ORDERED 2026-07-14 (Tray 1) | same board mechanically; drop-in on the display standoffs |
| Official 7" Touch Display | The face | OWNED | [clough42 reference model (thing:1646255)](https://www.thingiverse.com/thing:1646255) -- repo already has the official STEP/STL |
| Camera Module 3 | The eye (imx708) | OWNED | [CM3 Wide mockup (thing:6939162)](https://www.thingiverse.com/thing:6939162), CC BY-SA, DOWNLOADED to `reference/electronics/rpi-cam3-wide-mockup-6939162/` (mesh 25.0x23.9 = official 25x24 board; Wide lens barrel differs) |
| AI Camera (IMX500) | Eye upgrade: on-sensor NPU runs detection ON the camera, freeing Pi CPU/RAM for the brain (resolves the AWARENESS "AI camera" decision) | ORDERED 2026-07-14 (Tray 1) | 25x24 board like CM3 but DEEPER module + different lens barrel: the forehead cam pod (Ø6.3 lens bore + recess depth) is CM3-sized, so the pod needs a re-fit pass -- VERIFY_ON_ARRIVAL, keep CM3 as the modeled default until measured |
| Joy-IT RPI5-HEATSINK5 x2 | Head thermal (80C breaker trips under brain bursts) | ORDERED 2026-07-14 (Tray 1). **WARNING: 65x45x15 mm (+ 30x30x10 fan) EXCEEDS the verified official-cooler keep-out (63.5x42.5x13.7) on every axis, and the tilt-sweep margin was only 0.60 mm** -- re-run `tools/probe_cooler.py` with the Joy-IT envelope before installing in the head; if it fails, fall back to the official Active Cooler (envelope already verified) or duct the separate 30x10 fan at the louvres | dims from the [Joy-IT manual](https://joy-it.net/en/products/RB-Heatsink5) |
| Fan 5VDC 30x10 (B-3010-D05-MLA) | Spare / louvre-duct option if the Joy-IT cooler fails the head probe | ORDERED 2026-07-14 (Tray 1) | n/a |
| Gooseneck mics x2 + CM108 | Ears (Ø17 windscreen through head side walls) | ORDERED, not yet in inventory | none needed -- placeholder `ear_mic_L/R` |

## Motion

| Component | Role | Status | Reference model |
|---|---|---|---|
| 28BYJ-48 stepper x4 | Pan (2:1 spur), tilt (3-start worm), 2x antenna deploy | OWNED x6 (Bags 5, 14) | [MajicDesigns (thing:4919536)](https://www.thingiverse.com/thing:4919536) -- Fusion360 + IGES + STL; also [CastorX (thing:3247370)](https://www.thingiverse.com/thing:3247370) |
| ULN2003 driver x4 | Stepper drivers | OWNED x9 | [seandoughtie clearance model (thing:3781347)](https://www.thingiverse.com/thing:3781347), CC0 -- NOT downloaded (Chrome silently swallows this thing's download; grab manually if needed) |
| TT gearmotor 1:120 x2 | Track drive (2 more OPTIONAL for twin-drive) | OWNED x3 (Bag 5); buy 1 only for the 4th station | [CCFIVE yellow TT motor (thing:1079893)](https://www.thingiverse.com/thing:1079893), CC BY, DOWNLOADED to `reference/electronics/tt-motor-1079893/` (STL + STEP, 69.5x22.4x29.9); also [mademodeller (thing:4890871)](https://www.thingiverse.com/thing:4890871) |
| MX1588 H-bridge | Drives both TTs | OWNED x5 | none found; trivial 2-layer module, model from measurement |
| A4988 (Pololu) | No station yet. Option it enables: rewire a 28BYJ-48 bipolar (cut the red common) for ~+40% torque on pan or tilt if the 4:1/2:1 margins prove thin on hardware | ORDERED 2026-07-14 (Tray 1) | n/a |
| N20 gearmotor 6V (240RPM x4, 400RPM x2) | No station yet. Prime candidate: the deferred gripper-arm actuation (rack-and-sector parallel gripper, reference/hand-mechanism/) | ORDERED 2026-07-14 (Tray 1) | n/a |

## Sensors

Two planes since 2026-07-14: the **Sense HAT Rev2 rides the Pi's I2C bus** (it is a
Pi peripheral with kernel/python support, not an Arduino part) while the timing-
critical and 5V modules stay on the **Arduino I/O plane** (docs/AWARENESS.md).

| Component | Role | Status | Reference model |
|---|---|---|---|
| **Sense HAT Rev2 x2** | One board covers THREE former buy-list rows: LSM9DS1 9-DoF IMU (accel+gyro+MAG), LPS25H pressure/temp, HTS221 humidity/temp -- plus NEW capabilities: TCS3400 color/ambient-light sensor, 8x8 RGB LED matrix, 5-way joystick. All I2C (0x6a/0x1c IMU, 0x5c, 0x5f, 0x29 color, 0x46 matrix+joystick). Mounts REMOTELY on the chassis equipment base (65x56.5 HAT outline, M2.5 at the 58x49 pattern) fed by a thin I2C drop down the neck -- it can NOT stack on the Pi (no head clearance + the cooler owns that space), see firmware/WIRING.md. 2nd unit = spare / bench Pi | ORDERED 2026-07-14 x2 (Tray 1) | official; dims VERIFY_ON_ARRIVAL |
| Arduino Uno R3 | I/O plane: sonar timing, vibration, mmWave, touch, LEDs, reflexes; one USB to the Pi | OWNED x3 (Bag 6) | [DesignSpark CAD (thing:346338)](https://www.thingiverse.com/thing:346338), CC BY-SA, DOWNLOADED to `reference/electronics/arduino-uno-r3-346338/` (OBJ + RSDOC); also [1:1 replica (thing:6564384)](https://www.thingiverse.com/thing:6564384) |
| HC-SR04 x4 | Forward + rear obstacle, 2x cliff | BUY (none owned) | [dvemac (thing:3653635)](https://www.thingiverse.com/thing:3653635), CC BY, DOWNLOADED to `reference/electronics/hcsr04-dvemac-3653635/` (STL+STEP/SLDPRT+3MF, 45.2x18.5x26.5 = 45x20 board + barrels); also [markbenson OpenSCAD (thing:122136)](https://www.thingiverse.com/thing:122136), CC BY-NC, in `hcsr04-markbenson-122136/` |
| LD2410-class mmWave | Presence, boresight-forward behind the front hex grille | BUY | dims VERIFY_ON_ARRIVAL (LD2450 does NOT fit the bay) |
| BME688 | ~~Env sensing~~ DOWNGRADED to optional: the Sense HAT covers temp/humidity/pressure; buy a BME688 only if VOC/gas sensing ("room feels stuffy") is wanted | OPTIONAL (was BUY) | dims VERIFY_ON_ARRIVAL |
| MPU6050/ICM-20948 IMU | ~~Motion, near the pan axis~~ COVERED by the Sense HAT's LSM9DS1 -- off the buy list. NOTE the chassis_base IMU posts at (14,-12) become the Sense HAT seat in the next base iteration (cheap reprint by design) | COVERED (was BUY) | n/a |
| SW-420 | Vibration, hard pad at (-48,-95) | BUY | dims VERIFY_ON_ARRIVAL |
| TTP223 x2-4 | Cap touch (head-top pass deferred) | BUY | dims VERIFY_ON_ARRIVAL |

**I2C address note:** the Sense HAT's TCS3400 sits at **0x29, the same address as
the VL53L1X ToF** that was once a cliff-sensing candidate -- if a VL53L1X ever
joins the bus it needs its XSHUT re-address dance or a mux.

## Power (firmware/WIRING.md)

| Component | Role | Status | Reference model |
|---|---|---|---|
| 30W+ USB-C PD brick | Wall power | BUY (official 27W works marginally) | n/a |
| 12V PD trigger | Rear jack, sets the harness rail | BUY | n/a |
| XL4015-class 5A buck | Pi rail (trimmed 5.25V) on the belly tray | BUY (owned LM2596s are 2-3A class) | Thingiverse has only enclosures ([tag:xl4015](https://www.thingiverse.com/tag:xl4015)); board dims VERIFY_ON_ARRIVAL |
| MP1584 mini buck | Motor rail | BUY (a selectable-5V module could stand in) | enclosures only ([thing:5324190](https://www.thingiverse.com/thing:5324190) etc.); dims VERIFY_ON_ARRIVAL |
| Inline blade-fuse holder | 5A Pi-rail fuse (fuse itself OWNED, ATC/ATO assortment) | BUY holder | n/a |
| SK6805-2427 narrow strip 1m | Forehead LED slot (42x5 -- a standard 8x5050 stick does NOT fit) | BUY | n/a |

## Thingiverse download workflow

Thingiverse blocks headless downloads (search returns a React shell, `download:`
endpoints 401 without an app token), but **"Download all files" works anonymously in
a real browser**. Zips land as `<Name> - <thingId>.zip` with `files/` + `images/`.
Drop downloads into `reference/` with the thing URL + license recorded here; things
are individually licensed (usually CC variants) and the repo is public.

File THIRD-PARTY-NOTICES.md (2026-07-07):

# Third-party notices

Parviz's own source, CAD, and docs are Apache-2.0 (see `LICENSE`). The repository
also bundles third-party 3D models under `reference/`, each under its own license.
Those files are **not** covered by the Apache license. Attribution and terms below;
each source folder also keeps its original `LICENSE.txt` and `README.txt`.

| Bundled model | Path | Author | License | Used for |
|---|---|---|---|---|
| Tank track (thing:3062624) | `reference/tank-track-3062624/` | advancedvb | CC BY | Link pad, sprocket, and idler geometry |
| Yellow TT motor (thing:1079893) | `reference/tt-motor-1079893/` | CCFIVE | CC BY | Drive-motor placeholder dims |
| Official 7" Touch Screen reference model (thing:1646255) | `reference/rpi-7in-touchscreen-model/` | clough42 | **CC BY-SA** | The combined screen+Pi mesh the robot is built around |
| 7" touchscreen case (thing:1585924) | `reference/rpi-7in-touchscreen-case/` | luc_e | **CC BY-NC** | Style / fit reference |
| RPi Camera v2.1 model (thing:1564160) | `reference/rpi-camera-v21-1564160/` | jbeale | CC BY | Camera placeholder |
| Alexa-style smart display | `reference/alexa-style-smart-display/` | (style reference) | see folder | Original head-shape inspiration |

Additional references, not third-party redistributed CAD:

- **Raspberry Pi Camera Module 3** dimensions come from the official Raspberry Pi
  mechanical drawing (`reference/rpi-camera-module-3/`), © Raspberry Pi Ltd.
- **Concept renders** in `reference/design/` are AI-generated design references that
  set the black-and-orange look. They are direction, not redistributed third-party CAD.

## License-obligation summary

- **CC BY** (tank track, TT motor, camera): keep attribution. No other restriction.
- **CC BY-SA** (touchscreen model): keep attribution; derivatives *of that mesh* must
  stay under a compatible share-alike license.
- **CC BY-NC** (touchscreen case): keep attribution; that mesh may not be used
  commercially. This is the one term that constrains whole-repo redistribution to
  non-commercial use while the file is present.

To make the entire distribution cleanly permissive/commercial, remove
`reference/rpi-7in-touchscreen-case/` (CC BY-NC) and, if you also want to drop the
share-alike obligation, `reference/rpi-7in-touchscreen-model/` (CC BY-SA), then fetch
them at build time instead. The build only loads the pins-out STL from the touchscreen
model folder; the case folder is a style reference only.

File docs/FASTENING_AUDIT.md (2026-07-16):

# Fastening & Assembly Audit — post-print failure report (2026-07-15)

> **STATUS: COMPLETE, all gates green** (build · check · check-sweep · 62/62
> invariants · wallcheck · fits 64 contacts all expected · export · 20/20 plates
> slice clean). Fixed in 4 parallel worktrees (chassis / head / neck+pan / tracks),
> then items 6-14 finished in 2 more (2026-07-16). No thread-form pilot remains on
> any structural joint.
>
> **THE AUDIT UNDERSTATED THE DAMAGE.** It graded these joints "weak". On probing
> the built meshes, **NINE WERE DEAD AS MODELLED** -- the screw could never engage
> anything: two `chassis_base` stations had **no hull material at any z** (the
> glacis had eaten the floor, so `sub(pilot)` was a silent no-op), the cliff M2s
> engaged **0.30 mm** then hit undrilled solid, the ULN pilots stopped 3.0 below
> their post tops, and the **IMU posts had height ZERO -- they did not exist**.
> Root cause worth naming: **a derived feature next to a hardcoded partner**. When
> `chassis_clear` went 7 -> 10, every z-derived post moved and the hardcoded pilot
> depths stayed. The power-tray posts beside the ULN posts were fine -- because
> they derived their pilot.
> `checks.py` now gates exactly that: every fastener station must land on real
> material, probed as a RING at r=3 (an on-axis probe reads "void" for a healthy
> joint *and* for a hole drilled through thin air -- only the surrounding material
> distinguishes them). Verified to fail at the old dead coordinates, 0/8.
>
> **THE ROOT CAUSE WAS DEEPER THAN THIS AUDIT ORIGINALLY SAID.** The audit named the
> Ø2.5 thread-form pilots and told everyone to copy `chassis_pedestal`'s "reference
> good" hex traps. **Those were broken too.** A hex nut with its flats on the trap
> walls spans ACROSS CORNERS -- ac = AF*2/sqrt(3) = 6.35 for M3, not the 5.5
> across-flats -- along the insertion run, but the trap box ran FROM the bore axis
> AWAY from it. The nut could only ever reach axis+3.175, a miss of 2x the thread
> radius: **the screw could never catch it.** So the chassis's ONE real nut pocket
> never worked either. Probed on the built mesh, all 4 feet: nut-reaches-bore False
> before, True after. `geo.nut_slot()` now owns the correction (pass it the screw
> axis; it seats the nut on the bore, and the seat is what aligns it hands-free),
> and `checks.nut_reaches_bore()` gates the whole class -- verified to have teeth by
> rebuilding the old broken foot and watching it fail.
>
> Two more defects the fix pass found that this audit missed entirely:
> - **The gates were lying.** `make invariants`/`make wallcheck` read `stl/*.stl`,
>   which only regenerate under `EXPORT=1`, so both silently measured the PREVIOUS
>   geometry; `make all` ran them before its own export. Same class as the Stage 4
>   vacuous probe in docs/FIXES.md. Fixed: both now depend on a fresh `stls` target.
> - **The sprocket's M2 retaining screw was dead as modeled** -- 8.4 mm of solid hub
>   sat between the Ø6 bore and the socket, so it could never reach the shaft tip.
>
> Where geometry beat the plan (each probed, not guessed): the master-link captive
> M2 nut does not fit (5.50 usable vs 5.82 needed) -> heat-set inserts; the
> tilt_carrier did NOT need inserts (the audit assumed no nut face was reachable --
> probing disproved it); the tail seam moved y -88 -> -95 (no joint could exist at
> -88) and takes a tongue instead of a dowel; the head panel gets tab rebates, not a
> perimeter lip (at y -66 the wall is all corner curve). Details in each section.

User print feedback: (1) almost none of the screws/pockets work, (2) joints lack real
bolt+nut capture, (3) nothing holds parts aligned while driving screws, (4) parts
(tail + front counterpart) break at thin-ligament connections.

Four-subsystem code audit (chassis, head, neck/pan/tilt, tracks). Verdict below,
then the full per-joint tables.

## Systemic verdict

- **The failing class is the Ø2.5/Ø1.7 "thread-form pilot" into PLA** — 40+ joints.
  grep-confirmed: the whole chassis has exactly ONE real nut pocket (the pedestal
  foot traps); everything else self-taps into plastic.
- **The joints the user is NOT complaining about are exactly the engineered ones**:
  M4 road-wheel slide-up nut slots, M8 tower ledge+roof cages, pedestal side-slide
  hex traps + printed registration pins. That pedestal pattern
  (chassis.py:1330-1348) is the template to propagate.
- **Alignment is the second gap**: half-laps/dowels exist on some seams, but the
  load-bearing roots (neck→platform, head panel→frame, screen tray→wall,
  bezel↔back) have flat-on-flat interfaces with zero registration.
- **Fix patterns, in preference order**:
  1. Through-bolt M3 + side/slide-in captive hex nut trap (pedestal pattern) —
     wherever a nut face is reachable in assembly order (most joints qualify).
  2. M3 brass heat-set insert — where no nut face exists (blind bodies, exterior
     walls); bosses must grow to ≥Ø9 (Ø4.6 hole, ≥2.2 wall).
  3. Every screwed seam gets a locator: Ø4 dowel pair, tongue/groove, rebate lip,
     or spigot — so parts self-hold while screwing.

## P0 — unbuildable or missing as coded (fix before any reprint)

| # | Finding | Where | Fix |
|---|---|---|---|
| P0-1 | **Bezel↔back 8 "captive nuts" are SEALED inside the bosses — no insertion slot exists.** The head's primary structural joint cannot be assembled. | head.py:344-355 | Cut a slide-in nut slot from each back-boss flank (opens to interior); add 2 Ø4 dowels on the split plane |
| P0-2 | **y=−88 tail seam has NO joint at all** (bare butt plane, no pads/screws/dowels). This is the reported tail break. | chassis.py:590-592, 987-992 | Give it the y=26 joint (pads + dowel + captive nut) at x≈±48 + a tongue/shelf across the seam |
| P0-3 | **Tilt-axle grub pilots are Ø2.5 = M2.5 CLEARANCE size — zero thread engagement.** | head.py:181-191 | Replace with slit pinch-clamp + cross M3 bolt + hex trap (grubs in PLA strip on re-torque anyway) |
| P0-4 | **ant_bracket has NO mounting to the head** (spine just rests on the wall) and its 1.2 mm motor face plates already severed once. | head.py:811-874 | Add bosses/pins into frame walls; plates ≥2.5; motor ears → M3 through-bolt + nut on the open far face |
| P0-5 | **Front/rear obstacle HC-SR04 boards are unretained** (float against wall, gravity + wires). | chassis.py:42-61, 352-358 | 2 M2 posts or a slide-in board shelf clip behind each wall |
| P0-6 | **TT motor upper M3 = loose nut in a ~4 mm gap** — impossible with track installed, the exact hands-free failure reported. | chassis.py:394-396, 944-957 | Duplicate the lower screw's slide-up nut pocket for the upper (extend down the wall face) |
| P0-7 | **Sprocket axial retention assumes a Ø2 axial hole in the TT shaft — verify owned motors have it** (many variants don't). | tracks.py:320,345-346 | Verify; fallback hub grub-screw boss |

## P1 — thread-form pilots on structural joints → captive nuts / inserts

| Joint | Where | Nut face reachable? | Fix |
|---|---|---|---|
| neck_clevis → pan_platform (3× M3, root of the whole head stack, NO alignment) | neck.py:202-213, pan.py:98-111 | yes — bench, column-base top | Side-slide hex traps in column base + 2 registration pins |
| tilt_carrier → neck plate (4× M3x16, 4.0 mm thread in raised pads) | neck.py:146-162, 375-378 | no (buried vs motor can) | Heat-set inserts in pads/column |
| pan retainer ×6 → deck (carries all head uplift) | pan.py, chassis.py | yes, through the seat-wall mouths before race installation | M3x10 through-bolt + captive hex trap in deck |
| pedestal pan-motor ears (Ø2.5×16 pilots) | chassis.py:1299-1301 | no | Heat-set from top face |
| Lower front/rear seam y=+26 (2× M3x12 + counterbore leaves 1.0 wall) | chassis.py:624-658 | yes — open-top tub | Slide-up hex trap in −y pad; widen pad ≥18, root ≥3 |
| Deck hold-downs 4+4 (6 of them are the panels' ONLY top retention, 5.1 mm thread on scarfed bosses) | chassis.py:576-618, 902-915 | yes — under boss, pre-deck | Slide-in hex nut under each boss |
| Deck strip seams y=66/−52 (2× M3 per seam into 6 mm shelf) | chassis.py:994-1022 | yes — shelf underside | Hex recess opening down from shelf bottom; keep half-lap |
| Panel splice half-lap (1× M3x10, 5.5 mm thread; makes the track module rigid) | chassis.py:916-923 | yes — L-block bottom | Slide-in nut in the lower block; thicken 1.8 mm tongue cheeks |
| Panel L-feet → floor (Ø3.3 bore in 4.8 foot = 0.75 mm walls) | chassis.py:801-803, 959-979 | yes — belly underside | Through-bolt + hex recess at floor underside; foot ≥8 wide |
| belly_plate → hull rim (6× M3x10 csk) | chassis.py:495-515 | yes — boss tops face cavity | Hex trap at boss top |
| chassis_base → hull floor (4× M3, no dowels, and it's the only tail-seam tie today) | chassis.py:528-531, 1180-1185 | yes — 0.2 skin to belly face | Through-bolt + external hex recess + 2 dowels |
| Head panel→frame 6× M3 (flat-on-flat, no registration; rim tabs are break candidates) | head.py:531-546 | yes — tab inboard faces | Perimeter rebate lip on frame rim + hex pockets in tabs |
| Head frame↔frame top flange 2× M3 (no alignment between frames) | head.py:548-562 | yes — flange underside | Dowel/tongue at flange seam + nut slot from below |
| Bezel_L↔R seam pads (pilot side) | head.py:591-616 | yes — interior | Nut pocket opening into interior; keep dowels |
| screen_tray → back wall 4× M3 (heaviest module held by hand while driving blind from outside) | head.py:373-384, 663-669 | yes — pillar sides pre-insert | Locating spigots/shelf in head_back for the pillar ends + square-nut slots in pillars |
| Master-link keeper bars M2 into Ø1.7 pilot (the ONLY repeatedly-serviced M2-in-PLA) | tracks.py:216-247 | tight | Bayonet/snap keeper, or M2 + brass insert; else spec 2-3 reuse cycles max |
| Cliff HC-SR04 M2 pilots (strip on 2nd service) | chassis.py:1053-1067 | yes — pocket side | M2 nut + washer behind, or heat-set |
| mmWave tab M2 pilots | chassis.py:1097-1105 | yes — behind tab | M2 through + nut |
| BME688 Ø5×2 wall bosses (snap under driver torque) | chassis.py:532-544 | no (exterior wall) | Heat-set M2 or clip-mount |
| PD-trigger M2 edge-on into wall layers (weakest orientation) | chassis.py:301-310 | no | Heat-set or printed slide-in carrier |
| ULN2003 / power-tray / Arduino / IMU posts (Ø6 posts split on tapping) | chassis.py:1143-1259, neck.py:222-231 | mixed | Posts ≥Ø7 + heat-set, or M2.5 screws (low load) |
| tilt ULN2003 horizontal Ø6 bosses on column back | neck.py:222-231 | boss rear open | Ø7+ bosses + inserts or M2.5 |

## P2 — fragile ligaments (break-after-print register)

Chassis:
1. **Tail seam + corner crescents**: past |y|≈109 the r12 cavity-corner crescents are
   the hull's ONLY floor↔end-wall ligaments (chassis.py:747-752); both glacis end
   walls hang on them → add inboard gusset ribs (x ≤ 62). The 33° glacis/floor
   knife wedge on the tail chips in handling.
2. Panel L-feet 0.75 mm walls (chassis.py:959-964).
3. y=26 seam pad: Ø6.8 cb leaves ~1.0 wall; pad roots 1 mm into floor (654-657, 600).
4. Splice tongue 1.8 mm cheeks around the cb (818-820, 918-920).
5. mmWave 3.5 mm ceiling-hung tab (1097-1105); BME Ø5×2 bosses; led_front 1.2 base.
6. TT lower-nut pocket outboard web wall **0.6 mm** (955-956) → +0.4 minimum.
7. **M8 cage ROOF strip ~0.98 mm** spanning the ~24 mm tension window
   (chassis.py:880-886) — thinnest structural member in the running gear; thicken.

Head:
8. Frame rim tabs: Ø2.5 pilot through 9-wide tabs clipped by the corner curve →
   ~3.2 mm ligaments, sole panel retention (head.py:531-539).
9. Door hook plates 1.3 mm, layer-peel loading (463-472) → ≥2 + root fillet.
10. Door snap-tongue slit ends unradiused (crack starters), barb band 3.5 tall
    (478-512).
11. Bezel forehead pad hangs on a 3.2 ext bridge; chin dowel bore 2.6 from pad
    edge (591-616).
12. Bezel↔back boss walls 1.9 mm around the hex void (344-355).

Neck/pan/tilt:
13. **tilt_carrier rear wing 2.15 mm × 20 strip** + connectivity only through an
    x 8.8..17 band of a 4 mm plate (neck.py:349-358) — highest break risk here.
14. Carrier Ø7 bosses (1.75 wall) on 8 mm cantilever (364-368).
15. Historical finding: three uplift tabs, each 2.6x4.1x14, were the sole restraint
    against lifting the top-heavy head and loaded across print layers. Superseded by
    the one-piece full-circle retainer ring with six M3 lobes. The design load is about
    60 N for a 1.5 kg turret at 4g dynamic. At the 2.6 mm radial engagement plane, the
    continuous lip provides about 293x2.6 = 762 mm2 of shear area, versus
    3x14x2.6 = 109 mm2 for the former tabs, about 7.0 times more area.
16. Cheek tilt-stop leg 6×5×22 takes repeated stall-homing impact (neck.py:66-68).
17. Bearing hoop 3.07 mm radial wall + 0.15 press = split risk (neck.py:53,131);
    same for F688 0.05 press seats (tracks.py:440) — below FDM repeatability:
    coupon-calibrate or bore +0.05..0.10 with crush ribs.
18. Worm-support riser prongs ~3.1 wide (neck.py:107,176-180);
    trim_neckfoot 3.0 ring fragile until glued.

Tracks:
19. Keeper bar 1.9×2.2 section, 0.85 tab rim, 0.75 boss-pilot edge (tracks.py:211-247).
20. Master C-jaw crown 2.4 mm over the slotted bore, carrying full belt tension
    (219-222) — print master in PETG/PCTG.
21. Road-wheel hub cosmetic bolt circle: 0.6 mm ligament at the loaded hub
    (469-475) — delete or shrink the cosmetic holes.
22. Strip-boundary filament pins have zero axial retention (open Ø2.2 both ends,
    tracks.py:175-179) — melt-mushroom ends or step one bore to Ø1.6 press.
23. **SUPERSEDED 2026-07-16:** the 2026-07-15 PLA sawtooth bearing face was
    rejected because sustained M8 clamp load and desk heat can crush the teeth.
    A vertical M3 backstop ladder was probed first, but Ø3.4 bores at the required
    roughly 1.6 mm pitch overlap and remove their chain-load bearing walls; the
    8.0 mm tower width also cannot stagger 6.35 mm across-corners captive M3 seats.
    The implemented fallback deletes the teeth and recesses a flush 12x28x1.0
    steel strip under the inboard M8 nut face. Its captured ends spread creep load
    into the full PLA shoulders. This is creep mitigation, not a positive lock;
    inspect tension during early service and re-tension if the chain relaxes.

## P3 — misc / retention & registration

- pan_race: nothing stops ring rotation but friction → 2 anti-rotation nubs if it spins.
- tilt_worm on D-shaft: rearward retention = M5 penny washer trapped by the carrier
  plate bore lip (done 2026-07-15); forward retention = M3x3 cup-point grub through
  the worm hub onto the shaft flat (2026-07-16).
- pan_gears 32T: no axial retainer (gravity) — fine, monitor.
- M4 nut slide-up slots: nuts drop out when flipping the panel → crush-rib nib in
  each slot mouth. Bench note: nuts in BEFORE panel mounts (slots blind after).
- Wheels spin on the M4 thread band unless partially-threaded M4×40 → make it a
  hard BOM requirement.
- trim_neckfoot Ø3 pin sockets 3.5 blind → deepen; fascia/rear trim pins 2.5
  engagement → deepen to 5 or add snap barbs.
- 695-2RS hoop press: coupon first; fallback Ø13.05 bore + printed cap/circlip.
- 695-2RS axle journals: fully round at both seats; the center-only flat must not enter |x| 20..24.
- worm_wheel drive: M3x4 cup-point grub through a radial O2.5 pilot onto the center-only
  axle flat. Retention-grub exemption: threads hold preload and the tip-on-flat contact
  carries torque. Coupon first; reversal backlash remains a bench measurement.
- led_strip recess: no retention modeled — note glue in ASSEMBLY.md or add a lip.
- Stand-ins historical note: the M8 press-nut/tension defect was resolved 2026-07-16
  with real printed threads plus an outer jam nut on every tower; seam dowel
  Ø4.0-in-Ø4.0 remains jam-or-rattle → hole +0.1.
- Stale comments: tracks.py:461, 516-518 (deleted pod rails / nut ducts),
  chassis.py:706 (slot depth overstated).

## Assembly-holding gaps (nothing registers the parts while screwing)

1. neck_clevis on pan_platform — NONE (load-bearing root) → pins + traps.
2. head panel on frame — NONE (flat slab, 6 screws) → rebate lip.
3. frames L/R to each other — only the panel tongue, nothing frame-frame → dowel.
4. bezel on back — NONE (8× M3x35 blind) → 2 Ø4 dowels on the split plane.
5. loaded screen_tray in head_back — NONE (drops in, screwed blind from outside)
   → pillar spigot seats.
6. chassis_base in hull — loose relief pockets only → 2 dowels.
7. Track filament-pin joints — hand-held while threading → acceptable, but
   mushroom the ends.

Good examples already in-tree (reuse, don't reinvent): pedestal pins+traps (C2),
M4 slide-up slots, M8 cages, TT nub+tab 3-point location, deck half-laps,
y=26 dowels, door hook+snap, trim rail nut pockets (head.py:254-264).

## Nib retention (2026-07-16)

World Z is up. Parts are already modeled in assembled world coordinates. Repeated loop
sites are listed once with their full direction set.

| Slot | File:line | Mouth direction | Disposition |
|---|---:|---|---|
| Tilt-axle pinch clamps, pair | `src/head.py:276` | -Z | NIB: gravity-open headline fix |
| Bezel to back perimeter traps | `src/head.py:473` | inward +/-X and +/-Z | NIB on the two top traps with -Z mouths; side and bottom mouths are horizontal or gravity-seated |
| Back-panel rim tabs | `src/head.py:738` | +Z | NO-NIB: gravity seats the nuts |
| Head-back frame top flange | `src/head.py:765` | -Z | NIB: gravity-open before the screw starts |
| Bezel seam traps | `src/head.py:859` | -Y | NO-NIB: horizontal mouth |
| Screen-tray pillar traps | `src/head.py:934` | +/-X | NO-NIB: horizontal mouth |
| Antenna spine mounts | `src/head.py:1220` | +Z | NO-NIB: gravity seats the nuts |
| Antenna motor ears, upper/lower | `src/head.py:1234` | -Z/+Z | NIB on upper ear only: its mouth is gravity-open; lower ear is gravity-seated |
| Tilt-carrier upper nut blocks | `src/neck.py:239` | +/-X | NO-NIB: horizontal mouth |
| Tilt-carrier lower nut blocks | `src/neck.py:253` | +/-X | NO-NIB: horizontal mouth |
| Neck to pan-platform traps | `src/neck.py:333` | -Y, +X, -X | NO-NIB: horizontal mouths |
| Neck ULN board traps | `src/neck.py:386` | +/-X | NO-NIB: horizontal mouth |
| Pan clip trap | `src/chassis.py:323` | -Y | NO-NIB: horizontal mouth |
| Belly-plate rim traps | `src/chassis.py:655` | inward +/-X or +/-Y | NO-NIB: horizontal mouths |
| Deck hold-down traps | `src/chassis.py:800` | inward -X or +Y | NO-NIB: horizontal mouths |
| Lower-front seam traps | `src/chassis.py:838` | +Z | NO-NIB: gravity seats the nuts |
| Lower-tail seam traps | `src/chassis.py:885` | +Z | NO-NIB: gravity seats the nuts |
| Side-panel splice traps | `src/chassis.py:1272` | +Y | NO-NIB: horizontal mouth, then blocked by the mating panel |
| M4 road-wheel bolt-axle traps | `src/chassis.py:1281` | -Z | NIB: audit P3 flip-prone slots |
| Upper TT motor traps | `src/chassis.py:1333` | -Z | NIB: gravity-open slide-up slots |
| Front panel-foot traps | `src/chassis.py:1349` | inward +/-X | NO-NIB: horizontal mouth |
| Deck split-shelf traps | `src/chassis.py:1457` | +/-Y | NO-NIB: horizontal mouth, closed by the mating strip |
| Front deck motor-mount traps | `src/chassis.py:1585` | -Z | NIB: gravity-open M2 slots |
| Pan pedestal ear traps | `src/chassis.py:1831` | inward +/-X | NO-NIB: horizontal mouth |
| Pan pedestal base traps | `src/chassis.py:1880` | +/-Y | NO-NIB: horizontal mouth |

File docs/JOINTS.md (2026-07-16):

# Assembly joint contracts

This document defines when a Parviz joint is ready to print. Screw holes alone are not a
joint. Every interface between assembled printed parts must locate itself, reach one
deterministic seated pose, accept its complete fastener stack, and remain installable in the
documented assembly order.

The executable inventory is `src/joints.py`, built from the typed declarations in
`src/jointspec.py`. `src/joint_checks.py` evaluates those declarations against freshly
exported geometry. Run:

```bash
make jointcheck
```

The target first runs `make stls`, so it cannot silently validate an older export. It exits
nonzero on any failed contract and writes the full result to `web/joint_report.json` for
machine or viewer use. `make gate-tests` runs deliberately broken fixtures and proves the
reusable gates reject them. `make assembly-release` is the canonical final pipeline.

The pan uplift interface is `pan_retainer_to_chassis`, joining `pan_retainer` to
`chassis_deck_center`. Its continuous r45.4..48.0 lip locates over the platform
shoulder and six M3x10 through-bolts clamp six deck lobes into captive M3 nuts. The
ring installs after the platform: it drops vertically over the r45.0 top band because
the lip ID is 90.8 mm and the band OD is 90.0 mm. The contract probes the full lip,
all six screw stations and captures, and this collision-free insertion path.

The pan-motor mounting interface is `pedestal_to_belly`, joining
`chassis_pedestal` to `belly_plate`. Two printed Ø4 pins run in Ø4.2 obround plate
slots. They locate Y and rotation while leaving X tunable by
`+-pan_cd_adjust` to set spur-gear backlash. Four M3x12 countersunk screws pass
through matching X slots into captive pedestal nuts and clamp the selected
position. Their countersinks are swept across the full travel, so every screw
remains flush with the z=7 belly face at any adjustment. Assembly step 7 owns
the backlash-setting procedure and final clamp.

## What every declaration owns

Each joint has a stable ID used here, in `docs/ASSEMBLY.md`, and in the report. Its declaration
names:

- The fixed and moving parts, final transform, assembly direction, and approach distance.
- Required bearing/seating faces and the maximum seated gap.
- Locator type and dimensions: rail/groove, tongue/rebate, keyed boss, or separated pins.
- Fit class, printer clearance, minimum engagement, and end stop.
- Every screw, washer, nut or insert, clamped thickness, engagement, and allowed protrusion.
- Gravity-down captive-nut mouths use 0.25 mm crush-rib nibs. The head tilt-axle
  clamp pair and chassis slide-up axle slots retain their nuts before screw insertion;
  a bench pose is a convenience, not part of the joint contract.
- Nut/insert insertion direction and retention, plus driver/wrench/iron tool envelopes.
- The assembly step and the parts already present at that step.
- Minimum surrounding wall, boss, and load-path ligament dimensions.
- Any intentionally free degree of freedom, with its permitted range.

Coordinates and dimensions must come from the same named interface datums used to generate the
parts. Do not copy raw coordinates into a declaration. A copied value can let the geometry move
while its gate continues probing the old location.

## Release gates

The joint runner applies the following checks where their declaration data is relevant:

1. **Inventory completeness.** Every structural printed-part interface has one declaration;
   every named part and feature exists.
2. **Positive location.** A structural joint locates independently of its screws. A single
   round pin needs a separated rotation stop; flat-on-flat plus screws fails.
3. **Mating geometry.** Male and female features have the declared clearance, overlap,
   engagement, surrounding material, and bearing contact.
4. **Seated datum.** The insertion reaches one stop within translation, rotation, and face-gap
   tolerances without overshoot.
5. **Fastener stack.** Head seat, clearance bore, clamped material, nut/insert engagement,
   screw length, protrusion, and blind-hole bottom clearance are physically consistent.
6. **Nut and insert installation.** The captive element reaches the screw axis in the correct
   orientation, can enter from free space, cannot spin, and remains retained when handled.
7. **Tool access.** Driver, wrench, or heat-set tool envelopes reach the hardware at its actual
   assembly step without crossing installed material.
8. **Assembly path.** The moving part reaches its seated pose along the declared path without
   unintended collision; later parts do not seal required access.
9. **Pre-fastener stability.** Locators support and align the part before the first screw is
   installed, including against gravity in the documented orientation.
10. **Connectivity and load path.** Pins, rails, tabs, and bosses belong to the intended
    printable body and meet their minimum ligament/wall requirements.
11. **Fit class.** Every mating feature declares a removable, locating, press, rotating, or
    fastener-clearance fit. Nominal-equals-nominal geometry is not accepted implicitly.
12. **Joint section evidence.** Critical joints define section planes that expose locators,
    fastener stacks, clearances, and approach directions for human review.
13. **Adversarial mutations.** Missing locators, offset pockets, short engagement, sealed nut
    paths, bad screw lengths, and blocked tools each have a focused test that must fail.
14. **Release freshness.** Joint checks consume the same regenerated STL set used by the other
    print gates, before the final Bambu export and headless slice check.

Not every gate is purely mesh-based. Dimension and screw-stack relations should be checked
analytically from their shared parameters, then probes or intersections must confirm that the
declared bore, pocket, material, and access path exist in the exported mesh. Final-pose overlap
alone is insufficient for insertion and tool access.

## Maintenance workflow

When adding or changing a joint:

1. Add or update its shared interface datum and generate both mating features from it.
2. Update exactly one declaration in `src/joints.py`; do not hide a structural joint in an
   exception list.
3. Add focused good and known-bad tests for any new check behavior.
4. Run `make jointcheck`, then inspect every reported measurement and failure, not only the exit
   code.
5. Update the matching BOM and installation step in `docs/ASSEMBLY.md`.
6. Update this document if the contract model or reusable policy changed.
7. Before exporting print files, run `make assembly-release`.

Exceptions must be narrow and carry the physical reason, approving date, measured value, and a
replacement check. Bought bearings, intentionally rotating joints, snap fits, and low-load
electronics posts can need different constraints; they do not get an unmeasured blanket waiver.

The TT drive stack is one such narrow exception. The sprocket and side panel are printed,
but they mate only through the bought TT shaft and remain intentionally rotational in a
Ø12.5 journal around the Ø12 hub. Forcing this into the fixed printed-part `Joint` pattern
would invent a seated pose that does not exist. `checks.py` instead asserts the closed land
and cross-pin bore, while the interference and fit gates own the 0.25 mm radial running fit.

`track_shoes_to_side_panels` covers the four repeated hold-down joints. Each shoe seats
flat against the wheel-beam underside, but location comes from two separated Ø3 pins in
Ø3.4 bores. Two M3×10 countersunk screws rise from the running face into captive M3 nuts
at z 18.0. The mounted shoe closes the slide-up nut mouths, and upward track load bears
directly into the beam rather than loading the screws in tension.

Tilt drivetrain note: the tilt worm is torque-keyed by the 28BYJ double-D shaft, retained
rearward by the plate-seated M5 penny washer, and retained forward by an M3x3 cup-point grub
through the worm hub onto a shaft flat. The grub is bench-set and extracts with the cartridge.
The worm wheel has a round Ø5.2 bore and slides over either fully round 695 journal. Its
radial M3x4 cup-point grub is preloaded onto the axle's x +1.5..+11 center-only flat. The
flat carries reversal torque; the grub threads only retain preload. Loosen it before axle removal.

## Report interpretation

`web/joint_report.json` contains a schema version, summary, and one result per joint/check with
status, measured values, tolerances, and diagnostic text. A missing result is not a pass.
Consumers must reject an unknown schema version and a report whose inventory does not match the
current declarations. The runner should publish the report atomically after evaluation so an
interrupted run cannot leave a partial file that looks current.

`docs/FASTENING_AUDIT.md` remains the historical defect ledger for the first print. This file and
`src/joints.py` define the forward-looking policy and executable source of truth.

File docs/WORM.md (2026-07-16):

# Tilt worm drive, real tooth geometry

Real involute worm-drive geometry replacing the readable placeholders
(`gear_disc` / `worm` in `src/build.py`). Generated by
`tools/gears/gen_worm_drive.py`, verified by `tools/gears/verify_mesh.py`.

Files (both watertight, `mesh.is_volume == True`):

- `stl/neck/worm_wheel_real.stl`: 12T helical involute wheel, axis **X**, centered at origin
- `stl/neck/tilt_worm_real.stl`: single-start trapezoidal-thread worm, axis **Y**, centered at origin

## The numbers

| Quantity | Value | Why |
|---|---|---|
| Module | 1.25 | `PARAMS["worm_module"]` |
| Wheel teeth | 12 | `PARAMS["worm_wheel_teeth"]` (ratio 12:1) |
| Pressure angle | **25°** (not 20°) | 12T undercuts at 20° (limit 17.1T); at 25° the limit is 11.2T, so zero profile shift and full-strength roots. Both members are printed as a matched pair, so the nonstandard PA costs nothing. |
| Wheel pitch r | 7.500 | m·z/2 |
| Wheel tip r | 8.250 | stub addendum 0.6m = 0.75 (see core constraint below) |
| Wheel root r | 6.475 | worm addendum 0.875 + 0.15 clearance below pitch |
| Wheel face width | 7.0 | `PARAMS["worm_wheel_w"]` |
| Wheel bore | Ø5.2 through | axle Ø5 + clearance (blank only: no hub/tubes/grub, build.py adds those) |
| Wheel helix angle | 8.085° right-hand | **must equal the worm lead angle** (crossed 90° axes); a spur wheel would clash ~0.5 mm at the face edges |
| Worm starts | 1 | self-locking |
| Worm pitch r | **4.400** | derived, see below |
| Worm tip r / OD | 5.275 / **10.55** | worm addendum 0.7m = 0.875 |
| Worm root r / core | 3.500 / **Ø7.00** | wall for the double-D bore build.py cuts |
| Worm thread length | 14.0 | `PARAMS["worm_len"]`, exactly ±7 about origin |
| Axial pitch = lead | 3.92699 | π·m, fixed by the wheel |
| **Lead angle λ** | **8.085°** | atan(lead / (2π·4.4)) |
| **Center distance** | **11.900** | 7.5 + 4.4 (vs `worm_cd()` = 11.5 → **+0.40 mm**, see below) |
| Backlash | 0.25 circular | all taken on the wheel tooth (thinned at the pitch line) |
| Worm crest width | 1.147 mm | printable (> 0.6) |
| Wheel tip tooth width | ~0.97 mm | printable |

## Why CD is 11.9, not worm_cd()'s 11.5

Three constraints can't coexist: module 1.25 (fixes lead at 3.927), the Ø7
solid worm core (root r ≥ 3.5), and CD 11.5 (worm pitch r 4.0). With pitch r
4.0 the whole thread depth budget below the pitch line is 0.5 mm, leaving the
wheel ~0.35 mm of usable addendum, no real tooth engagement. Resolving in
favor of meshing physics: worm pitch r = root 3.5 + wheel addendum 0.75 +
clearance 0.15 = **4.4**, so **CD = 11.9**. The worm axis drops 0.4 mm relative
to the axle; `worm_cd()` is the single source of truth for the bracket AND the
assembly, so it propagates as a one-line change.

## Why the lead angle is 8.1°, not < 4–5°

At module 1.25 single-start, λ = atan(3.927 / (π·d_pitch)). Hitting λ ≤ 4.5°
needs worm pitch Ø ≥ 16 → CD ≥ 15.5, blowing both the OD and the bracket. The
< 4–5° rule is for steel-on-steel (μ ≈ 0.07–0.10). Self-locking requires
μ > tan λ · cos α = **0.129**; printed PLA-on-PLA runs μ ≈ 0.3–0.4 dry, so the
drive self-locks with 2–3× margin. Caveat: heavy grease (μ ≈ 0.1) makes it
marginal, if lubricating, use a light dry film or rely on the balanced head
(near-zero back-drive torque by design; CLAUDE.md: "pre-balance the head so
the worm barely works").

## Verification results (2026-07-07)

- Both STLs: `is_watertight = True`, `is_volume = True`.
  Wheel bounds ±(3.5, 8.25, 8.25); worm bounds ±(5.275, 7.0, 5.275). Pitch
  radii check out (tip r = pitch r + addendum on both members).
- **Static mesh check** (wheel at origin axis X, worm axis Y at z = −11.9,
  wheel phase scanned over one tooth pitch): minimum boolean intersection
  **0.0000 mm³** (placeholder was < 30 mm³); worst deliberately-misaligned
  phase 16.1 mm³ (tooth-on-crest, as expected).
- **Engagement proof** (zero overlap ≠ floating apart): shrinking CD by 0.10 mm
  produces first flank contact (0.003 mm³), 0.30 mm gives 0.41 mm³, flanks sit
  ~0.1 mm apart at nominal CD, i.e. exactly the designed backlash.
- **Hand check**: opposite-hand wheel helix can't find a zero-interference
  phase (min 0.75 mm³); the exported right-hand pair can.
- Visual: `.claude/renders/worm_mesh_section.png` / `worm_mesh_zoom.png`
  (x=0 section, pitch circles tangent, crests centered in gaps, no crossings).

## How to regenerate

```bash
cd tools/gears
uv venv .venv --python 3.10          # any >= 3.10; system python3 is 3.9
uv pip install --python .venv/bin/python -r requirements.txt
cd ../..                             # run from the repo root (output paths)
tools/gears/.venv/bin/python tools/gears/gen_worm_drive.py
PYTHONPATH=tools/gears tools/gears/.venv/bin/python tools/gears/verify_mesh.py
```

Route note: bd_warehouse (the "preferred" build123d route) only generates spur
gears, no helical wheel, no worm, so the pair is generated from first
principles: numpy involute outline → manifold3d **twisted extrude**
(`Manifold.extrude(..., twist_degrees=7.596)`) for the wheel; a trapezoidal
rib swept along the helix + core cylinder, manifold-booleaned and trimmed, for
the worm. OpenSCAD/BOSL2 is not installed on this machine.

## Integration notes for src/build.py (not applied, do this in a follow-up)

1. **`worm_cd()`** (line ~420): return
   `P["worm_module"] * P["worm_wheel_teeth"] / 2 + 4.4`  (= 11.9).
   Cleaner: add `PARAMS["worm_pitch_r"] = 4.4` and use it. Everything keyed
   off `worm_cd()` (bracket, cradle, motor pose, `wz`) moves 0.4 mm down
   automatically. Update `PARAMS["worm_od"]` 10.0 → 10.55 for honesty (it
   only feeds the placeholder radius today). The cradle's Ø11.8 thread-relief
   bore still clears: new tip r 5.275 < the 5.34 it was sized for.
2. **Wheel** (line ~1703): replace
   `wheel = gear_disc(wheel_r, ..., axis="x")` with
   `wheel = trimesh.load(stlp("worm_wheel_real.stl"), force="mesh")`.
   Keep everything after it unchanged: the hub/spacer-tube union, the Ø5.2
   bore re-cut (harmless, the blank already has it), and the grub pilot all
   still apply. The blank is centered at origin, axis X, exactly like
   `gear_disc` output.
3. **Worm** (line ~1720): replace
   `wm = worm(P["worm_od"] / 2, P["worm_len"], axis="y")` with
   `wm = trimesh.load(stlp("tilt_worm_real.stl"), force="mesh")`.
   Keep the tail-stub union and the `dbore_neg` subtraction (flats ±X)
   unchanged. Core is Ø7.0, so the Ø~5.2 D-bore leaves a 0.9 mm wall, thin
   but adequate; the D-flats carry the torque. The thread span is exactly
   14 mm (the placeholder's ribs overhung 1 mm per end; envelope shrinks
   slightly).
4. **Render phase**: tooth/thread clocking now matters visually. The wheel's
   meshing phase depends on the worm's y-offset (the wheel plane crosses the
   worm at worm-local y ≈ +6 in the assembly). To render without fake
   interference, scan the wheel rotation about X over one tooth pitch (30°)
   for minimum boolean intersection and bake that phase in, see
   `mesh_check()` in `tools/gears/gen_worm_drive.py` for the exact snippet.
   `EXPORT=1` should export these real parts under the existing
   `worm_wheel` / `tilt_worm` names (they're print/buy parts now, not
   placeholders).
5. **Print notes**: wheel prints on its face (teeth are near-vertical walls,
   7.6° twist is fine); worm prints vertical (axis Z on the bed): the 25°
   flank angle is self-supporting. Grease the mesh lightly; design clearance
   doubles as the reservoir.

## 3-start regeneration record (2026-07-13)

PARAMS `worm_starts` = **3** (ratio 12:1 -> 4:1, 22.5 deg/s tilt; tradeoff notes in
params.py / CLAUDE.md). The committed `*_real.stl` pair IS the 3-start generation:
same m 1.25 / pitch r 4.4 / CD 11.9 / 12T wheel / PA 25 deg; lead 11.781, **lead angle
23.081 deg** (NOT self-locking), wheel helix matched (22.79 deg twist over the 7 mm
face), backlash 0.25 circular, crest width 1.147 (printable). OD 10.55 / core Ø7
unchanged so cradle/carrier interfaces carry over. Verification: static min
intersection 0.000 mm3 at CD 11.9; coupled full-worm-rev sweep (wheel follows at 3
teeth/rev) max 0.000 mm3; contact onset between CD-0.05 and CD-0.10; wrong-hand wheel
7.41 mm3 (direction confirmed). Assembly clocking constant in build.py: 24.5 -> 17.75.
`gen_worm_drive.py` reads STARTS from PARAMS and writes `stl/neck/worm_real_meta.json`;
`worm_real_ok()` (src/gears.py) compares meta to PARAMS and falls back to placeholders
on ANY mismatch -- the honesty gate is the sidecar now, not `worm_starts != 1`.
FDM caveat: flank gap measures ~0.05-0.10 radial (tighter than the pan spurs); confirm
the first printed pair doesn't bind at +0.1 oversize before greasing.

## worm_len 13 + end-chamfer regeneration (2026-07-13 evening, Pi 5 cooler pass)

PARAMS `worm_len` = **13.0** (was 14.0) and the generator grew a **0.6 mm 45 deg crest
END CHAMFER** on both thread ends (`END_CH` in gen_worm_drive.py, implemented as a
per-ring radius clamp in the helix sweep, recorded in the meta as `end_chamfer`).
Why: at the -33.8 nose-down tilt stall the Pi 5 active-cooler keep-out's swung rear
face reaches y = -20.0 + 0.669(z - 131.5); the old front thread end (y -17, crest
bottom z 135.8) penetrated ~0.1 and the Ø5 tail stub past it +2.7. New span: world
y -30.5..-17.5 (full crest to -18.1), stall margins +0.81 full-crest end / +0.64
chamfer edge (tools/probe_cooler.py reports tilt_worm -0.61). The wheel contact
plane (y -18) keeps 0.5 mm of full flank past it; the rear trim (-31 -> -30.5) is
dead thread (wheel-envelope overlap ends ~-22.9). `WORM_LEN` now reads from PARAMS
(single source of truth). Assembly knock-on: worm center stays y -24 (build.py's
plate-face offset 9.5 -> 10.0 and thread-start gap 3.5 -> 4.0, so plate/motor/
carrier/can-pocket all HOLD at face_y -34.5); the TAIL STUB union in build.py is
GONE -- the tail is now carried by a crest-riding r5.5 half-groove in the neck
(build_neck_clevis), riding the thread crest envelope at 0.225 radial clearance.
Verification (same tooling): both meshes watertight; static min intersection 0.000
mm3 at CD 11.9 (worst deliberate misphase 16.5); hand check wrong-hand 7.40 mm3;
contact onset between CD-0.05 and CD-0.10 (unchanged); coupled full-worm-rev sweep
0.000 mm3; assembly-pose zero window center **17.88 deg** (build.py clocking
constant, was 17.75). Wheel blank unchanged (byte-identical regeneration).
Wallcheck: tilt_worm.stl p1 0.25-0.27 = thread RUN-OUT FEATHERS where the helical
rib meets the flat trim faces (machined worms carry the same edge unless a run-out
relief is cut) + crest grazing rays; unloaded dead-thread ends, prints vertical
(bottom wedge on the bed, top wedge tip-rounded by the slicer) -- dispositioned as
a documented whitelist floor of 0.2 in src/wallcheck.py, not a generator defect.

## Fallback single-start pair (self-locking)

The 3-start pair remains the default because it delivers about 22.5 deg/s, but its
tilt torque margin is only about 1.3x and its 23 deg lead back-drives. The assumed
residual imbalance is about 25 mNm, while the physical head could exceed 100 mNm.
The committed 1-start pair restores mechanical self-locking and is a drop-in for the
same cartridge, center distance and axle. Physics decides between them on the bench.

Regenerate and verify the fallback from the repository root with:

```bash
STARTS=1 OUT_SUFFIX=_1s tools/gears/.venv/bin/python tools/gears/gen_worm_drive.py
STARTS=1 OUT_SUFFIX=_1s PYTHONPATH=tools/gears tools/gears/.venv/bin/python tools/gears/verify_mesh.py
STARTS=1 OUT_SUFFIX=_1s PYTHONPATH=tools/gears tools/gears/.venv/bin/python tools/gears/probe_worm_sweep.py
```

The sidecar records starts 1, module 1.25, 12 wheel teeth, worm pitch radius 4.4,
face width 7.0 and worm length 13.0. The 2026-07-16 verification reported both
meshes watertight and volumetric, correct-hand minimum 0.0000 mm3 at 10.5 deg,
wrong-hand minimum 0.7457 mm3, and contact onset at CD-0.10 with 0.0026 mm3.
The assembly-pose probe found a 9/121-step zero window centered at **25.50 deg**.
The correct coupled direction, sign -1, stayed at **0.0000 mm3** penetration over
49 steps and one full worm revolution. Sign +1 deliberately fails because it is
the wrong kinematic direction.

To swap, set only `PARAMS["worm_starts"] = 1`, rebuild, and print only
`tilt_worm.stl` and `worm_wheel.stl`. The cartridge, center distance and axle stay
unchanged. Tilt speed drops from 22.5 to about 7.5 deg/s and the ratio changes from
4:1 to 12:1, restoring self-locking. The starts-keyed filenames and matching meta
honesty gate prevent stale geometry from loading. With a stalled or dead motor,
drive the head fully up before pulling the cartridge, the old extraction rule for
the self-locking pair applies again.

## Pan spur pair (2026-07-13)

`tools/gears/gen_pan_spurs.py`: m 0.8, PA 20 deg, **32T** (width 5.0, D-bore cut in
build.py on the motor shaft flats) + **16T** (width 5.5, fused into the pan_platform
shank), CD 19.2, backlash 0.20 circular split 0.10/member, full-depth teeth (tips
13.6 / 7.2, roots 11.8 / 5.4). 16T undercut is a non-issue against a 32T mate (pair
limit ~14.2T). Verification: static 0.000 mm3, zero window centered 5.625 deg (half a
32T pitch, stored in the meta as `gear32_mesh_deg`), coupled sweep over one pinion
pitch 0.000 mm3. Cluster reach 32.8 <= 33.0 budget (race ID 34); deck gear pocket runs
0.9 clear. Meta sidecar `stl/neck/pan_gears_real_meta.json`, gated by `pan_real_ok()`.
NOTE: the 32T clocking assumes `pan_shaft_azim` = 180 -- re-derive if the azimuth moves.

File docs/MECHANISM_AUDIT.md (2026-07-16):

# Mechanism audit

Verified 2026-07-16 against freshly generated STL and GLB geometry. A render is not
accepted as proof: each row names the geometric or executable evidence that protects it.

| Group | Interfaces checked | Result and evidence |
|---|---|---|
| Track links and master links | 64-link loop, six hinge pairings, ±35° articulation, PIP pins, boundary pins, keeper retention | PASS. `tools/probe_track_pip.py`: all 6 pairs × 30 angles clean, 0.349 mm minimum clearance. The master joint contract verifies locator, M2 insert retention, insertion and load path. |
| Sprockets, idlers and road wheels | Conjugate link action, keel channels, F688 seats, M8 tension stack, M4 shoulder axles | PASS. 18-phase × 5-link sweep has 0.0000 mm³ penetration and a 2.14 mm skip barrier. M8x70 spans jam nut, tower, washer and inner nut. The M4 shoulder prevents wheel clamping. |
| Chassis and side panels | Tub seams, panel splice/feet, deck seams, belly plate, equipment base and pedestal | PASS. Joint gates cover registration before screws, stacks, capture and driver access. Invariants probe dowels/tongues, nut paths and supporting material. Wheel beams and towers are integral to the panels. |
| Pan bearing and drive | 18-ball cage/race, three clips, platform locator, 32T:16T involute pair and hard stops | PASS. Real-gear metadata matches parameters and the generated pair has a 0.0000 mm³ coupled sweep. All pan extremes through ±90° pass interference checks. |
| Tilt axle and worm | 695 seats, D-key, thrust stack, carrier registration, 3-start worm/12T wheel and stops | PASS. `tools/gears/probe_worm_sweep.py` reports 0.0000 mm³ on the coupled motion. The carrier joint verifies four M3 fasteners, locator, insertion and load path. All tilt extremes through ±30° pass. The printed axle remains an interim substitute for steel. |
| Head, screen and door | Bezel/back seams, panel rebates, tray rails/pillars, camera cover, hooks and snap tongues | PASS. Head contracts verify locators, nuts, stacks, access and material. Invariants probe hooks, freed tongues, screen pattern and service openings. Open the door near neutral tilt. |
| Antenna drives | Motor double-D, two compound stages, idler journal, fused output/pinion, rack, bracket and guide | PASS after repair. Disconnected preview discs became eight separately exported involute parts. Every part is one watertight body. Both static trains have 0.0000 mm³ tooth interference; an 11-position coupled sweep covers the full 50 mm travel below 0.02 mm³. |
| Plastic hardware stand-ins | M4/M8 threads, shoulders, F688 bushings, pan rollers, axle and dowels | PASS as interim hardware. ISO forms, clearances, grooves/crush ribs and shoulders are covered by `tests/test_hardware_standins.py`. Metal remains preferred for strength, wear and creep. |

## Whole-assembly evidence

- `make gate-tests`: 20 tests pass.
- `make invariants`: 62/62 invariants pass.
- `make jointcheck`: 261/261 gates pass across 18 structural joints.
- `make wallcheck`: all 66 exported parts meet the wall gate or a documented gear/thread edge floor.
- Neutral assembly: no unapproved overlap above 0.01 mm³.
- Motion envelope: all 14 isolated poses pass, including ±90° pan × ±30° tilt corners.
- Fit map: 140 close pairs and 12 press fits; every touching pair is expected.
- Stability: 52.8° worst tip angle and 82× fast-pan overturning margin.

Optional arms are excluded deliberately. `ARMS=1` enables visual placeholders only;
`docs/ARM-MECH.md` is a future design brief, not a verified printable actuator.

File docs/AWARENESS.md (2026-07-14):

# Parviz awareness architecture (design intent, 2026-07-12)

The robot is called **Parviz**. The core idea: Parviz is **aware of its
surroundings at all times**. A continuous stream of sensory data is fused
into a compact world state, a summary of that state is fed to an LLM, and
the LLM's output decides what Parviz does (expression, motion, speech,
escalation). Nothing sensory leaves the robot by default: **always listen,
always process locally, and call a more intelligent AI model only for
specific tasks or when the user asks for it.**

## Sensor suite (target)

| Sense | Hardware | Status | Feeds |
|---|---|---|---|
| Hearing (stereo) | 2x 3.5mm gooseneck mics in the head ears + CM108 USB adapters | ordered | VAD, wake word, local ASR, sound direction (L/R level diff) |
| Vision | Camera Module 3 (imx708) in the forehead; **AI Camera (IMX500) ordered 2026-07-14** -- on-sensor NPU runs detection on the camera itself, decision resolved (cam pod re-fit VERIFY_ON_ARRIVAL) | CM3 owned; IMX500 ordered | person/face detect ON-SENSOR, motion, scene description on demand |
| Obstacle / cliff | 4x HC-SR04 (front + rear obstacle, front + rear cliff, modeled in the chassis) | buy list | reflex layer, never waits for the LLM |
| Temp / humidity / pressure | **Sense HAT Rev2** (LPS25H pressure/temp + HTS221 humidity/temp), on the chassis equipment base via the neck I2C drop; BME688 now only if VOC/gas is wanted | ordered 2026-07-14 | ambient log ("room feels stuffy" needs the optional BME688) |
| Tilt / angle / accel | **Sense HAT Rev2** LSM9DS1 9-DoF (accel + gyro + magnetometer -- compass heading is new) | ordered 2026-07-14 | fall/pickup detect, incline, heading, head pose sanity |
| Light / color | **Sense HAT Rev2** TCS3400 ambient light + color | ordered 2026-07-14 | lights-on/off events, day/night rhythm, "someone turned the lights off" |
| Vibration | piezo/SW-420-class or the IMU's accel stream | candidate | desk knocks, being handled |
| Presence / micro-motion | mmWave radar (LD2410/LD2450-class): detects a still person by breathing | candidate | occupancy even when vision is off/dark |
| Touch | capacitive touch pads + the 7" touchscreen (done: face reacts to touch) + **Sense HAT 5-way joystick** (hidden physical input on the base) | screen done; joystick ordered | petting/attention events, service-menu input |
| Odometry | TCST1103 photo-interrupters on the drivetrain | candidate | dead reckoning for track moves |

The Sense HAT also brings an **8x8 RGB LED matrix** (an OUTPUT, not a sense):
mounted on the equipment base it is invisible with the deck on, so treat it as
a service/debug display (world-state heartbeat visible when the deck is lifted)
unless a later pass gives it a window.

## Tiered processing (the efficiency contract)

**Tier 0, reflexes (no model, <10 ms):** cliff = stop, obstacle = stop/avoid,
over-tilt = motors off. Hard-coded in the motion daemon; the LLM is advisory
and can NEVER override a reflex.

**Tier 1, always-on local perception (continuous, cheap):** per-sensor
daemons run constantly: VAD + wake word on the mic stream (openWakeWord /
whisper.cpp tiny-class), mmWave presence, IMU events, environment polling,
periodic low-res camera motion checks. Output = timestamped EVENTS into a
shared world state, not raw streams. Audio is transcribed locally; raw audio
is never stored or uploaded.

**Tier 2, local LLM tick (the ambient brain):** a summarizer turns the world
state into a compact text digest (most recent events + rolling context).
The digest goes to the LOCAL model, llama.cpp `llama-server` with
Qwen3-0.6B-class GGUF (measured on the Pi 5 2GB: 21 tok/s generation,
0.94 s for a short reply, fits alongside the face in RAM, see
software/README.md). It runs on a slow tick (seconds) plus event triggers,
and answers one question: *what should Parviz do right now?* Output is a
constrained action vocabulary: set_expression, look_at, say, move, log,
escalate, do_nothing (most common answer). **The face is an LLM output
device**: the expression shown and where the eyes/head look come from
these actions, not from local heuristics. Only reflex-speed overlays stay
local in the face process (idle blink, pupils tracking an active touch);
the brain's set_expression/look_at wins otherwise, so the face needs a
control channel (local socket) the brain writes to.

**Tier 3, escalation (rare, explicit):** only for specific tasks or when
the user asks: real conversation, scene understanding ("what's on my
desk?"), planning. Goes to a bigger model (Claude API or a model on the
Mac/VPS). The escalation payload is the world-state digest + the specific
request, still not raw sensor streams. Offline = Tier 2 keeps working,
Tier 3 features degrade gracefully.

## Data flow

```
mics ─ VAD/wake/ASR ─┐
camera ─ detect ─────┤
mmWave/IMU/BME/touch ┼─ events → WORLD STATE (rolling, in-RAM) ─ summarizer
HC-SR04 ─ reflex ────┘        (reflexes act directly)              │ digest
                                                                   ▼
                              action bus ◄─ local LLM (llama-server, ~0.6B)
                              │ set_expression / look_at / say / move / …
                              ▼                    │ escalate (rare)
                    face / neck / tracks / TTS     ▼
                                        remote brain (Claude API / Mac)
```

## RAM budget (the hard constraint, Pi 5 2GB -- 8GB ORDERED 2026-07-14)

face ~130 MB + local LLM server ~0.9 GB (0.6B, ctx 2048) + whisper-tiny
~0.2 GB + daemons/summarizer leaves ~0.4 GB headroom. This is exactly why
the ambient model is 0.6B-class: the 1.7B ceiling model fits ONLY alone,
not next to the ears. Bigger ambient brains mean a bigger-RAM Pi or an
accelerator, not a config change.

**Both halves of that sentence were ordered 2026-07-14:** a Pi 5 **8GB**
(the bigger-RAM Pi -- the 1.7B-class ambient model plus a larger ASR now
fit NEXT TO the face, with room for longer context) and the **AI Camera**
(the accelerator -- detection moves onto the sensor's NPU, freeing the CPU
share the 1-2 Hz vision loop eats today). Re-run the software/README.md
benchmarks on the 8GB board when it arrives; the 0.6B numbers stay valid
as the fallback/2GB profile.
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

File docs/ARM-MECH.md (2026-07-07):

# Arm mechanism (task #20): rigid vs posable vs actuated

Scope: the two gripper arms built by `build_arms()` in `src/build.py`. They mount on the head's
side rails (rail face x ±107.5, arm plane x ±127, standoff span 19.5 mm), so they ride the pan
AND tilt joints. Every option below is judged against the tilt worm drive, the joint that
actually carries them.

## Measured baseline (from the neutral-pose geometry, not the posed GLB)

Computed by loading `build_arms()` directly (the committed `web/assembly.glb` is posed at
pan 22 / tilt -12, which skews per-arm centroids; neutral-pose numbers below).
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

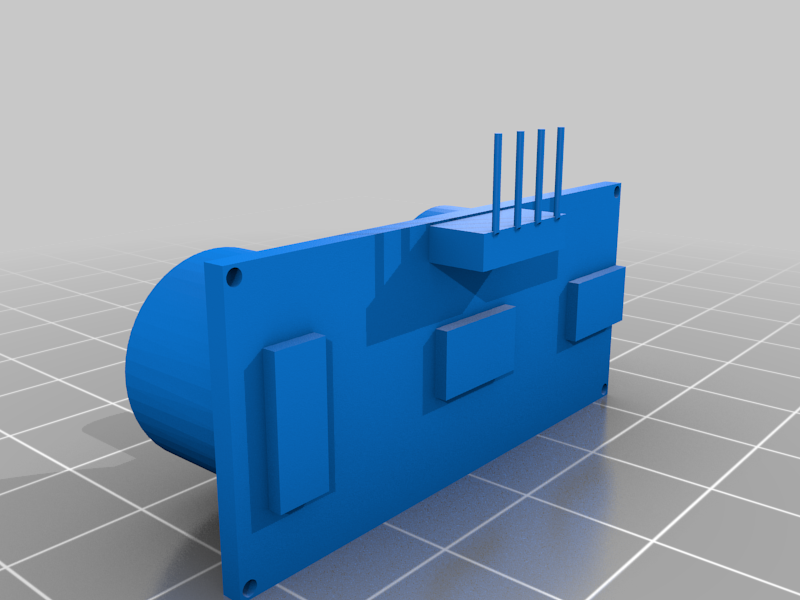
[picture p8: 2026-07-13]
reference/electronics/hcsr04-dvemac-3653635/images/b16901dc36818231f09446cea5ab84c1.png

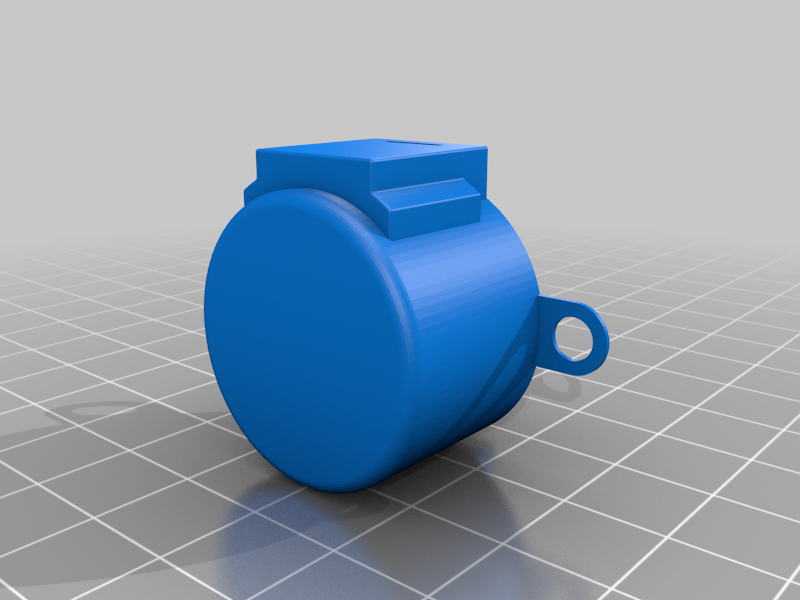
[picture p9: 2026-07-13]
reference/electronics/stepper-28byj48-4919536/images/Stepper_Motor_28BYJ-48_v2.png

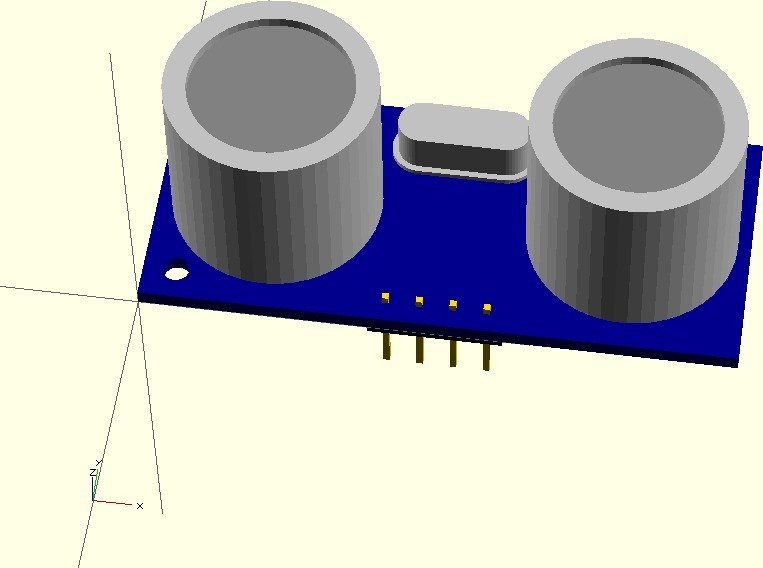
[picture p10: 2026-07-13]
reference/electronics/hcsr04-markbenson-122136/images/hc-sr04-ultrasonic-sensor.jpg

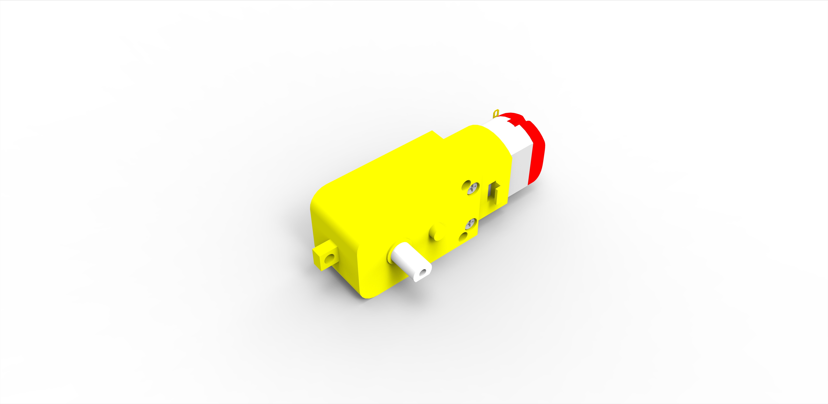
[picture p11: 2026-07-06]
reference/electronics/tt-motor-1079893/images/untitled.67.jpg

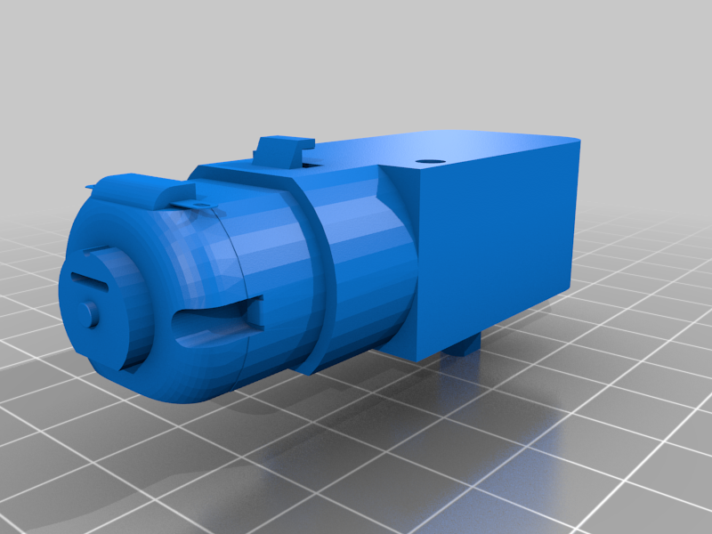
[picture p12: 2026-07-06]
reference/electronics/tt-motor-1079893/images/DC_Motor_20mm.png

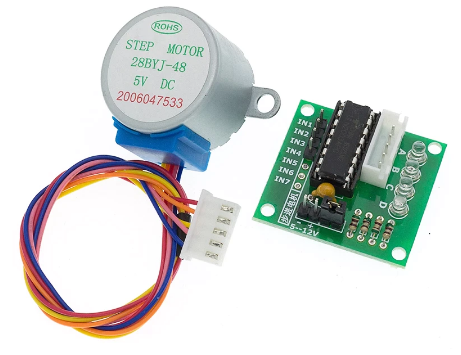
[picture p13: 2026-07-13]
reference/electronics/stepper-28byj48-4919536/images/Stepper_Hardware.png

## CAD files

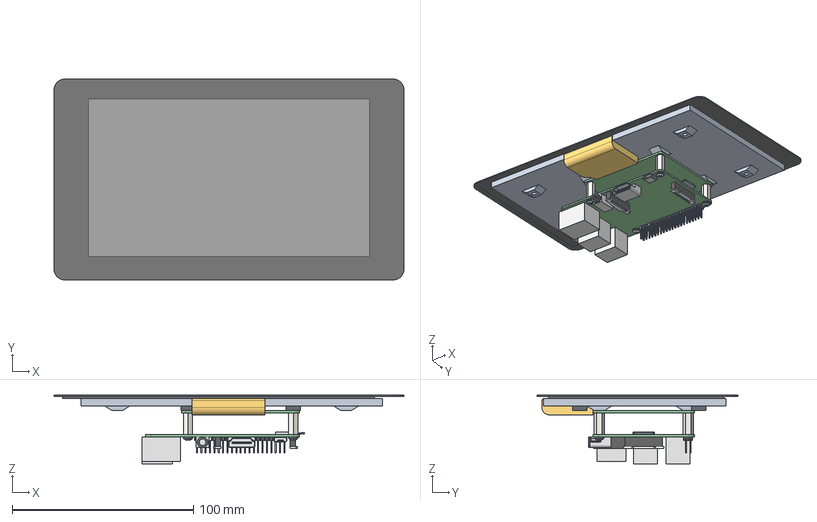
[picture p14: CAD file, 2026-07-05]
reference/rpi-7in-touchscreen-model/files/Raspberry_Pi_Touch_Screen_Assembly_-_Pins_Out.step
193.0 x 110.8 x 38.0 mm
RPi Display Driver PCB v1
RPi Touchscreen Module
Standoff M2.5 12mm v2 x 4
RASPBERRY PI 3 v2
M2.5 Screw x 4
micro_sd_card

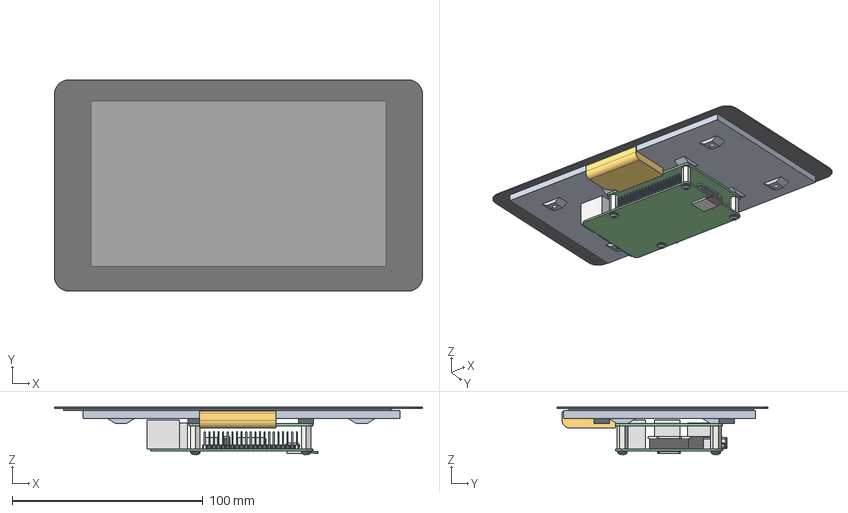
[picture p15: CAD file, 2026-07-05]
reference/rpi-7in-touchscreen-model/files/Raspberry_Pi_Touch_Screen_Assembly.step
193.0 x 110.8 x 25.0 mm
RPi Display Driver PCB v1
RPi Touchscreen Module
Standoff M2.5 12mm v2 x 4
RASPBERRY PI 3 v2
M2.5 Screw x 4
micro_sd_card

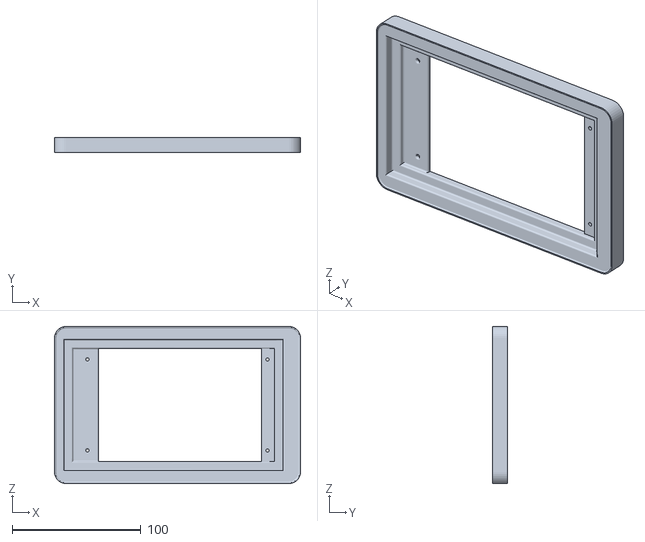
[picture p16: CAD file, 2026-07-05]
reference/alexa-style-smart-display/Front - screen mount.stl
191.3 x 12.0 x 122.2

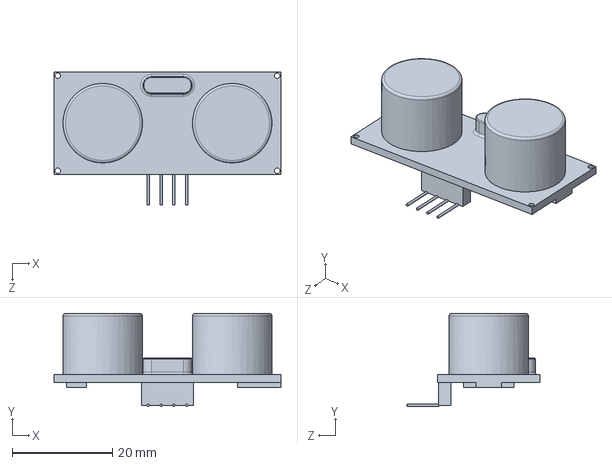
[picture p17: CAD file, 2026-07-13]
reference/electronics/hcsr04-dvemac-3653635/files/HC-SR04.SLDPRT
45.2 x 18.5 x 26.5 mm

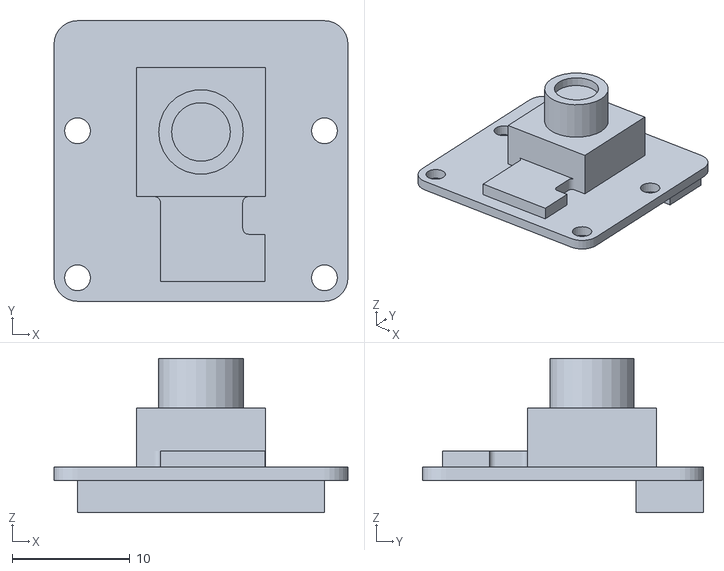
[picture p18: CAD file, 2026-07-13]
reference/electronics/rpi-cam3-wide-mockup-6939162/files/rpi-cam-3w.stl
25.0 x 23.9 x 13.1

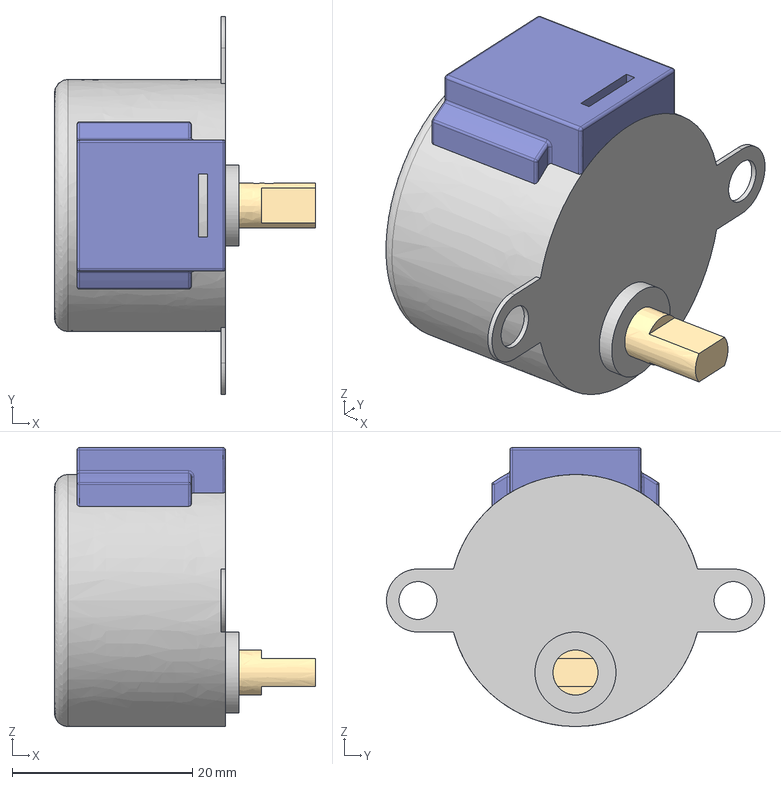
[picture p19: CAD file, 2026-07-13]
reference/electronics/stepper-28byj48-4919536/files/Stepper_Motor_28BYJ-48_v2.iges
29.0 x 42.0 x 31.0 mm

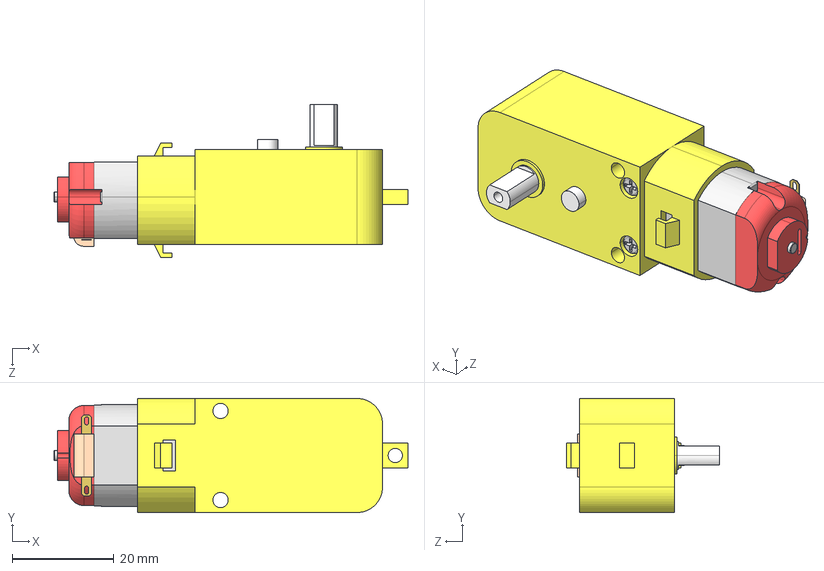
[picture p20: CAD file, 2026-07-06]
reference/electronics/tt-motor-1079893/files/DC_Motor_20mm.STEP
69.5 x 22.4 x 29.9 mm

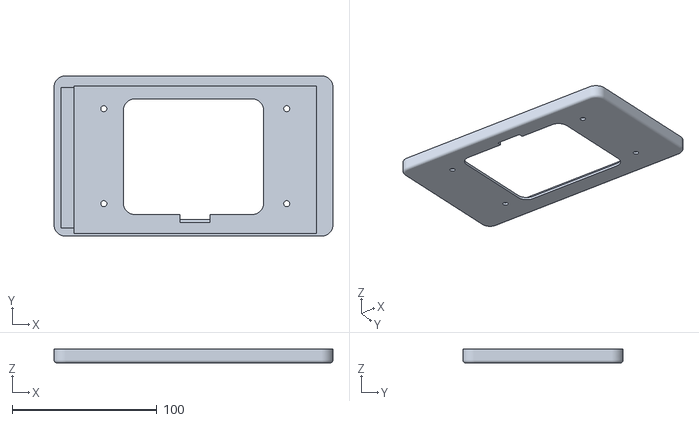
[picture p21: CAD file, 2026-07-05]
reference/rpi-7in-touchscreen-case/files/Raspi7inch_Front.stl
193.0 x 111.0 x 9.60

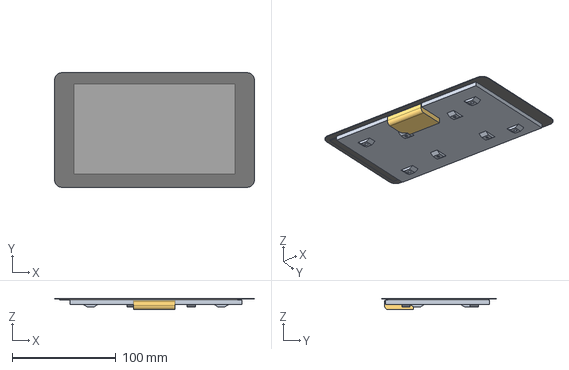
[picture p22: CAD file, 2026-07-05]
reference/rpi-7in-touchscreen-model/files/RPi_LCD_Module_v8.step
193.0 x 110.8 x 11.0 mm

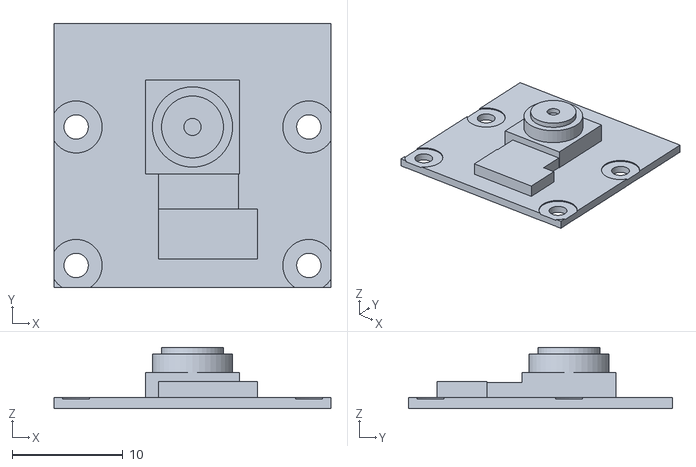
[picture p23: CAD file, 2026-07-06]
reference/rpi-camera-v21-1564160/files/RPiCam-v2-topside.stl
25.0 x 23.9 x 5.55

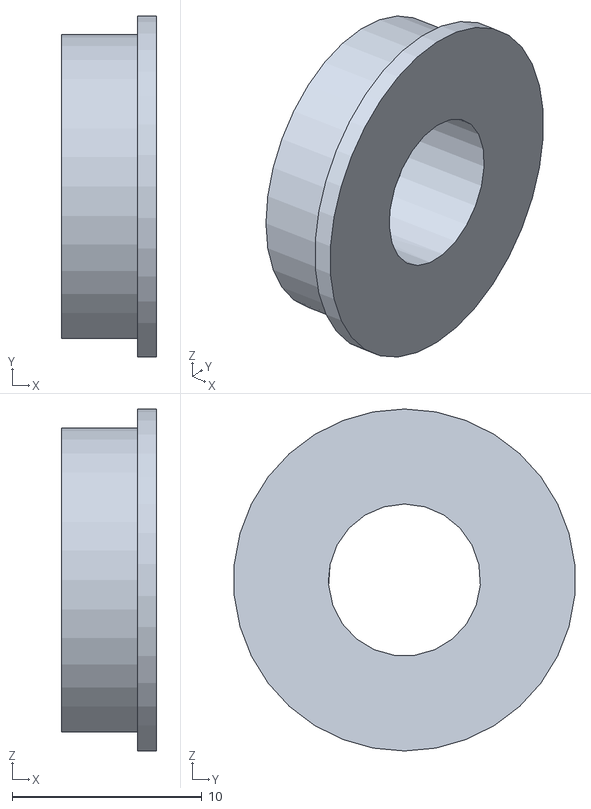
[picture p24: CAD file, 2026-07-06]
reference/tank-track-3062624/files/bearing_size.stl
5.00 x 17.9 x 18.0

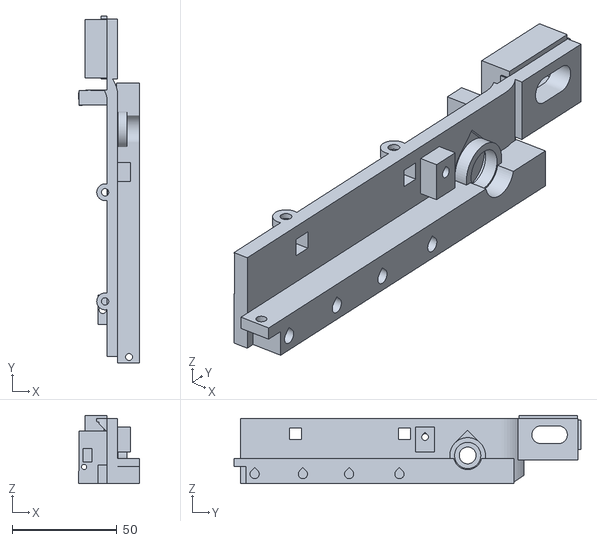
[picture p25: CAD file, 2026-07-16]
stl/base/chassis_side_R_front.stl
29.1 x 165.4 x 32.6

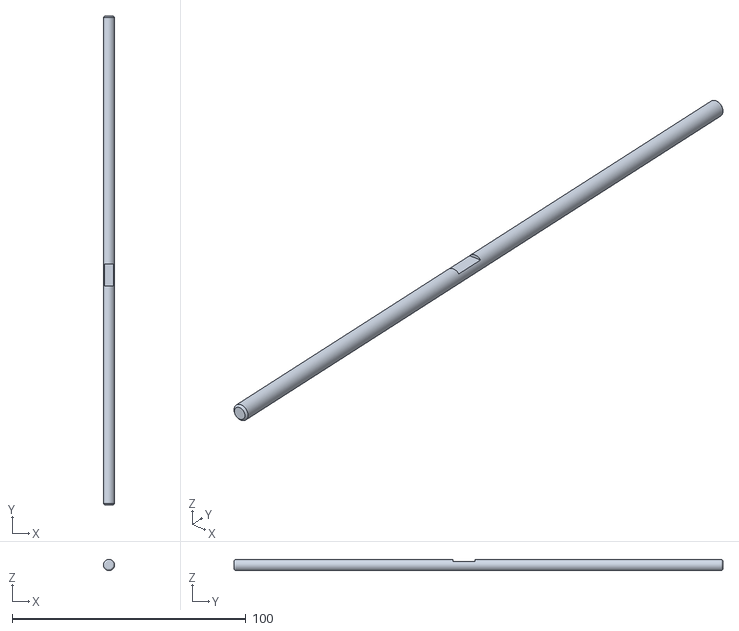
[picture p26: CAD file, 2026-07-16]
stl/hardware/hw_tilt_axle.stl
4.80 x 209.0 x 4.80

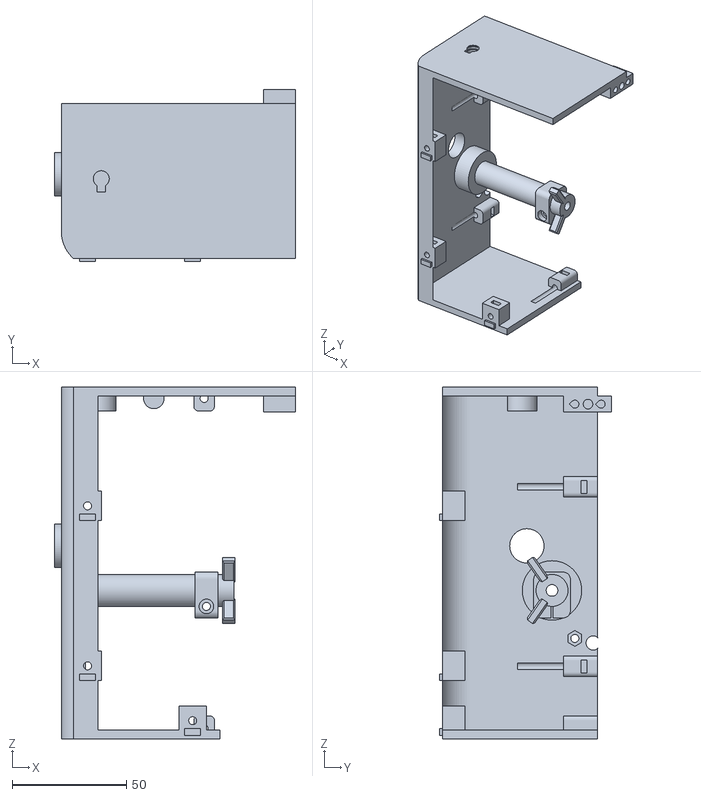
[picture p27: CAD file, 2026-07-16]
stl/head/head_back_frame_L.stl
105.5 x 75.2 x 154.0

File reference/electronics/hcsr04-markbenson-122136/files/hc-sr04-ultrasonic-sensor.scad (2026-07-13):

//HC-SR04 Ultrasonic distance sensor module

//Mark Benson

//23/07/2013

//Creative Commons non commercial

difference()
{
	union()
	{
		color("DARKBLUE")cube([45,20,1.2]);
		translate([16/2+1,18/2+1,1.3]) ultrasonicSensor();
		translate([16/2+27+1,18/2+1,1.3]) ultrasonicSensor();
		color("SILVER")translate([45/2-3.25,20-4,1.3]) xtal();
		translate([(45/2)-((2.45*4)/2)+0.6,2,-0.2]) rotate([180,0,0]) headerPin(4);
	}

	union()
	{
		color("DARKBLUE") translate([2.5,2.5,-1]) cylinder(r=2/2, h=3, $fn=50);
		color("DARKBLUE") translate([2.5+40,2.5+15,-1]) cylinder(r=2/2, h=3, $fn=50);
	}
}

module ultrasonicSensor()
{
	union()
	{
		//Sensor body
		color("SILVER")
		difference()
		{
			//Body
			translate([0,0,0]) cylinder(r=16/2, h=13.8, $fn=50);
			//Hole in body
			translate([0,0,0]) cylinder(r=12.5/2, h=14, $fn=50);
		}

		//Insert to indicate mesh
		color("GREY") translate([0,0,0]) cylinder(r=12.5/2, h=13, $fn=50);
	}
}

//ultrasonicSensor(); 

module xtal()
{
	//Xtal maximum dimensions for checking model
	//color("red")translate([0,0,-1]) cube([11.5,4.65,1]);
	//color("red")translate([(11.54-10.3)/2,(4.65-3.8)/2,0]) cube([10.3,3.8,3.56]);
	
	union()
	{
		//Base
		hull()
		{
			translate([0,0,0]) cylinder(r=4.65/2, h=0.4, $fn=50);
			translate([6.5,0,0]) cylinder(r=4.65/2, h=0.4, $fn=50);
		}
	
		//Body
		hull()
		{
			translate([0,0,0]) cylinder(r=3.7/2, h=3.56, $fn=50);
			translate([6.5,0,0]) cylinder(r=3.7/2, h=3.56, $fn=50);
		}
	}
}

module headerPin(numberOfPins)
{
	for (i = [0:numberOfPins-1])
	{
		color("GOLD") translate([(i*2.54),0,-2]) cube([0.5,0.5,8]);
		color("BLACK") translate([(i*2.54-2.54/2+0.25),-2.54/2+0.25,0]) cube([2.54,2.54,1]);
	}
}

//headerPin(4);

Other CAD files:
stl/neck/neck_clevis.stl
reference/rpi-7in-touchscreen-case/files/Raspi7inch_Lid_Velcro_1cm_HDD_Rest.stl
reference/rpi-camera-v21-1564160/files/RPiCam-v2.stl
reference/tank-track-3062624/files/fake_motor.stl
reference/rpi-camera-v21-1564160/files/RPiCam-v2.scad
reference/electronics/hcsr04-dvemac-3653635/files/HC-SR04.STL
reference/electronics/hcsr04-dvemac-3653635/files/HC-SR04_v1.f3d
reference/electronics/stepper-28byj48-4919536/files/Stepper_Motor_28BYJ-48_v2.f3d
reference/electronics/stepper-28byj48-4919536/files/Stepper_Motor_28BYJ-48_v2.stl
reference/electronics/tt-motor-1079893/files/DC_Motor_20mm.STL
reference/rpi-7in-touchscreen-case/files/Raspi7inch_Case.stl
reference/rpi-7in-touchscreen-case/files/Raspi7inch_Case_SD_Access.stl
reference/rpi-7in-touchscreen-case/files/Raspi7inch_Front_Split_Left.stl
reference/rpi-7in-touchscreen-case/files/Raspi7inch_Front_Split_Right.stl
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

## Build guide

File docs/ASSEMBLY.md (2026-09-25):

# Assembly

Current assembly notes for the tracked desk-pi prototype. The task #28 insertion/torque-path
audit (2026-07-07) verified a complete install order exists (see "Assembly order (verified)"
below). The 2026-07-08 maintenance pass then killed the worst service traps: tilt motor is a
rear-access cartridge (`tilt_carrier`), the worm wheel uses an accessible radial grub on a
center-only axle flat, tracks close with a master link (no loop-flexing), the pan race got a BB cage, both
joints got stall-homing hard stops, the microSD swaps through a plugged left-wall slot, the
positively located side-panel joints, and power is a 12 V PD-trigger + dual-buck belly tray
(firmware/WIRING.md). Grub-on-flat backlash remains a bench measurement covered by the coupon below.

## Bill of materials

Owned quantities cross-checked against a personal parts inventory (2026-07-07; re-audited
2026-07-13 with bag-label photo reads: TT motors, M8, 608zz, F688 candidates, fuses all
settled below). "Need" is per robot.

### Electronics

| Part | Spec / where it goes | Need | Owned | Buy |
|---|---|---|---|---|
| Raspberry Pi 5 | 2 GB, rides the display's own 58x49 standoffs | 1 | 1 (Tray 1) |, |
| 7" touchscreen | official kit; 4 factory M3 mounts (126.2x65.65) | 1 | 1 (Tray 1) |, |
| Camera Module 3 | recessed forehead, 4x M2 at 21x12.5 | 1 | 1 (Tray 1) |, |
| 45-65W USB-C PD brick | must advertise 15V (mandatory at 45W per PD power rules; fixed 12V is optional on generic bricks); the robot bucks 15V down internally. The official 27W brick is a 12V FALLBACK only, with the strict firmware co-scheduling rules load-bearing again -- power review 2026-07-16, firmware/WIRING.md | 1 | 0 (27W owned = fallback) | **1** |
| USB-C PD trigger board | set to 15V (12V only for the 27W fallback); mounts on the rear-wall M2 pilots beside the USB slot | 1 | 0 | **1** |
| XL4015-class 5A buck, CC/CV variant | Pi rail (trim to 5.25V, CC pot set to 5.0A -- the CV-only board has no current limit and does not satisfy the hard-limiting rule); 40x20 post grid on the belly-plate tray | 1 | 0 | **1** |
| MP1584-class mini buck | motor rail 5V; zip anchors beside the main buck | 1 | 0 | **1** |
| Polyfuse 2A hold / ~4A trip (MF-R200 class) | in series with the MX1588 VCC feed on the tray: a dual TT stall trips it and self-recovers instead of folding the shared brick (firmware/WIRING.md "Hard current limiting") | 1 | 0 | **1** |
| JST-XH kit + crimper | every joint-crossing / board run is a keyed XH plug | 1 | 0 | **1** |
| 18 AWG silicone pair + 5A blade fuse + inline holder | Pi-rail run + inline fuse at the tray | 1 m | fuse: OWNED (ATC/ATO blade assortment, settled 2026-07-13); wire + holder: 0 | **1 m wire + 1 holder** |
| 28BYJ-48 stepper | 5V, pan + tilt + 2x antenna drives | 4 | 6 (Bag 14) |, |
| ULN2003 driver | one per stepper | 4 | 9 (3 Bag 14 + 6 Bag 5) |, |
| TT gearmotor 1:120 | track drive, one per pod, shaft on X into the sprocket; +2 OPTIONAL for the twin-drive front stations | 2 (+2 opt) | **3 (Bag 5, re-audited 2026-07-13; the old "own 1" was stale)** | , (**1** only if the optional 4th station is populated) |
| MX1588 dual H-bridge | drives both TT motors, skid steer | 1 | 5 (Bag 7) |, |
| WS2812 forehead segment | 8 LEDs in the `led_slot` recess: **42 x 5 mm, 1.5 deep** (model dot pitch 4.6). A standard 8x5050 stick is 53.3 x 10.2, it does NOT fit. Buy a narrow (4–5 mm wide) addressable strip (SK6805-2427 / WS2812-2020, ≥160 LED/m) and cut an 8-LED segment, or widen `led_slot` to ~54 x 11 for the common stick | 1 seg | 0 | **1 m narrow strip** (also covers the front strip, next row) |
| Front white strip | 7 dots at 5 mm pitch in a 36 x 2.5 lip (`fled_*`): either 7x 3 mm white LEDs or a second segment cut from the same narrow WS2812 strip | 1 | 0 | covered by the strip above (or 10x 3 mm white LED) |
| Amber indicator LEDs | 2 corner lamps, 12 x 7 windows (`lamp_*`): 2 rectangular amber LEDs (2x5x7) or 5 mm amber behind a printed lens | 2 | 0 | **2–5** |
| HC-SR04 ultrasonic | x4 since the 2026-07-10/11 sensor passes (this row used to say "optional x1", stale): forward + rear obstacle (grille rings, Ø16 barrel passes at 26 mm c-c, `us_dx`=±13) + 2 cliff (deck slopes). With the Arduino I/O plane (docs/AWARENESS.md) plain 5V HC-SR04 is fine; HC-SR04P (3.3V) only needed if wired straight to Pi GPIO | 4 | 0 | **4** |
| Rear pod audio | rear Ø14 cylinder pod (`rear_cyl_*`): an owned Ø12 active buzzer fits for beeps. For real audio, buy a **MAX98357A I2S amp** and drive the owned 8Ω 0.5W mini speaker (Bag 15) from inside the chassis, the speaker is ~40–50 mm and can't live in the pod; the pod becomes the grille | 1 | buzzers: 5x active 5V (Bag 1) + 4x ~12 mm (Bag 16); speaker: 1 (Bag 15) | **1x MAX98357A** (only if speech/audio wanted) |
| Arm actuation | placeholder arms, TBD pending the arm mechanism pass. If actuated: 9x 9g servos owned (5x T-8090, 3x SG90, 1x MG90S) | TBD | 9 servos | nothing yet |

### Bearings, race, axles

| Part | Spec | Need | Owned | Buy |
|---|---|---|---|---|
| 695-2RS | 5x13x4, tilt-axle cheeks | 2 | 30 (Bag 13) |, |
| F688ZZ flanged | 8x16x5, flange Ø18; END idlers (both loop ends are free idlers since the 2026-07-11 mid-drive), **2 per wheel x 4 wheels** (one pressed at each face, Ø15.95 through-seat + Ø18.5x1.0 flange recess both sides). The Bag 13 "Miniature Ball Bearings" were checked as a candidate 2026-07-13: label reads **10pcs MR105 ZZ** (5x10x4, unflanged) -- wrong part | 8 | 0 | **8** |
| 6 mm airsoft BBs | pan race, Ø80 circle, `pan_race_n`=18. Printed-race acceptance test: assembly step 9 (reject -> commercial ring below) | 18 | 0 | **smallest bag (100+)** |
| Metric O-ring 6.0 x 1.0 | antenna gland and positive park grooves; NBR or silicone, silicone preferred for low breakaway; VERIFY_ON_BENCH | 2 | 0 | **2** |
| Commercial thin-section lazy-Susan / 4-point turntable bearing | **OPTIONAL print-3 upgrade** for the printed PLA race (buy only if step 9 acceptance fails). Pitch circle as close to Ø80 as available (typical cheap: 70 mm or 3" Al/steel lazy-Susan rings, or a thin-section slewing ring with **ID >= 68** so the cable pass and 16T pinion hub stay clear). Height budget = current printed stack seat floor -> platform underside (`_pan_stack` in `src/pan.py`): `pan_race_ring_t` 5.0 + air gap (`ball_d` - 2 * `pan_groove_engage`) 2.4 = **7.4 mm** (absolute: seat_floor = base_h - pan_plate_t - 7.4, plate_bot = base_h - pan_plate_t; with base_h 66 / pan_plate_t 7.6 that is z 51.0..58.4). Dims VERIFY_ON_ARRIVAL; fitting needs re-cut deck seat + platform underside (not modeled now; see step 9 upgrade path) | 1 | 0 | **only if printed race fails acceptance** |
| Ø5 SOLID rod | tilt axle, **209 mm** silver steel (**NOT tube**: a 1.0 flat on a Ø5/Ø2.5 tube leaves a 0.25 wall). File one **9.5 mm long x 1.0 ±0.1 mm deep center-only flat**, axle x +1.5..+11.0. Its center is **98.25 mm from the +X rod end**. Finished across-flats is 4.0 mm: a 4.1 GO slot must pass and a 3.9 NO-GO slot must not. Both 695 journals at |x| 20..24 and both head-clamp lands remain fully round | 1 | 0 | **1** |
| M8x**70** bolts + NYLOC nuts | END BOLT-AXLES: head = outboard hubcap, smooth journal through both F688s, thread begins at x=78 and crosses the tower clamp stack. M8x60 is too short to reach the NYLOC insert. | 4+4 | 0 | **4x M8x70 + 4 NYLOC** |
| M8 JAM NUTS + washers | **Required and modeled:** one AF13 jam nut bears on each tower's outboard face; the washer and NYLOC bear inboard. This closes the previous 17.4 mm air gap, clamps the tension slot/tower, and leaves the idler free on the smooth journal. The printed export likewise contains 8 total M8 nuts. | 4+4 washers | 0 | **4x M8 jam nut + 4 washers** |
| 12x28x1.0 steel strip | Front tension-slot nut bearing insert, cut square from mild-steel stock. Presses flush into the x62 face recess; captured ends spread sustained clamp load into the tower shoulders. This mitigates PLA creep but is not a positive axle lock | 2 | 0 | **2x** |
| 608zz | **not used** in the current design. SETTLED 2026-07-13: the bag label reads **"10pcs-608ZZ"** -- real 608ZZ bearings under translucent shrink wrap, not plastic rings. Still don't design around them | 0 | ~10-30 (608ZZ, confirmed by label) |, |

### Fasteners and pins

| Part | Spec | Need | Owned | Buy |
|---|---|---|---|---|
| M3 screws + hex nuts | captive-nut joints everywhere; incl. M3x35 x8 bezel↔back and **6x M3x10 + 6 M3 nuts for the pan retainer**. **2026-07-15 fastening campaign: ~+58 M3 hex nuts** as failed thread-form pilots became captive traps. Screw length changes: y=26 seam M3x12 → **M3x20**, neck→platform M3x12 → **M3x14** | lots | 540pc M3 stainless kit + 175pc M3 30–50 mm kit + 600pc M2-M5 kit + 1263pc M2-M4 kit (all Tray 1) | , (kits cover it) |
| M3×10 countersunk screws + M3 hex nuts | track hold-down shoes, 2 per shoe × 4. Heads recess flush in the z 10.4 running face; nuts slide up into the wheel beam at z 18.0. M3x10 (not x12): the beam clearance bore is capped at z 21.0 to keep 0.8 of wall under the sprocket journal. The front `spr_y2` pair is fittings-ready and only required when twin drive is populated | 8+8 (4+4 for rear-only drive) | covered by M3 kits | , |
| M3x3 cup-point grub | tilt-worm forward axial retention; seats through the O2.5 radial hub pilot onto a 28BYJ shaft flat | 1 | 0 (screw kits do not list grubs) | **1** |
| M3x4 cup-point grub | worm-wheel drive; radial O2.5 hub pilot, cup tip preloaded on the center-only axle flat, head flush with the Ø11 hub OD | 1 | 0 (buy with the M3x3 grub above) | **1** |
| M2/M3 brass heat-set inserts | **16 total, and a soldering-iron insert tip.** Used ONLY where a captive nut was probed and measurably does not fit: **4x M2** track master-link keepers (below), **8x M2** cliff HC-SR04 (a 3.8 mm skin at 33.7 deg has no room behind), **2x M2** PD-trigger (edge-on into wall layers = the weakest thread orientation), **2x M3** rear panel L-feet (boxed on all four axes by the BME board, the tail pad, the TT gearbox and the glacis: 5.70 window vs 6.80 needed). Everywhere else the campaign uses a real captive nut -- probing DISPROVED the audit's insert calls twice (tilt_carrier, pedestal ears). All VERIFY_ON_ARRIVAL: vendor OD/length varies, re-key `keeper_insert_*` / `foot_insert_*` before printing | 12x M2 + 2x M3 (+2 spare) | 0 | **16 inserts + 1 insert tip** |
| M2 brass heat-set inserts (detail) | **track master-link keepers** (2/master x2 = 4). The captive M2 nut does NOT fit: the pocket is boxed between the jaw slot's tension wall and the neighbour A-knuckle = 5.50 mm usable vs 5.82 needed across-corners (measured, tracks agent). Inserts need 5.40. This is the one repeatedly-serviced M2-in-PLA joint, so self-tapping was never going to survive the service cycles | 4 | none | **4x M2 brass heat-set + a soldering-iron insert tip**. VERIFY_ON_ARRIVAL: vendor OD/length varies, re-key `keeper_insert_{d,l}` before printing masters |
| M5 penny washers | tilt worm thrust seat (OD 15, ID 5.3, t 1.0): closes 2.0 mm of worm float (≈3° tilt slop) to 0.1. A direct shoulder is impossible because any ID under the Ø10.55 crest blocks cartridge extraction | 2 | check the owned washer assortment | 2x M5 penny washer (OD ~15) |
| Ø4 dowels | seam/joint registration so parts self-hold while screwing (the audit's "nothing holds it" class). +3 head (2 bezel↔back split plane, 1 Ø4x14 flange), +2 neck→platform printed pins, + existing y=26 pair. Tail seam uses a 6x12x4 **tongue** instead (no room beside the bore in a 10.2 pad; more shear area anyway) | ~8 | printed stand-ins in stl/hardware (Ø3.9) | Ø4x12 metal dowels x4 (or keep printed) |
| M2 screws | camera board (2 screwed + 2 locating pads) + cam_cover (2) + track master-link keepers (2/pod, **M2×8 pan head**, sunk in the tab counterbores) + PD-trigger mount (2) | 8+ | in the 600pc M2-M5 and 1263pc M2-M4 kits |, (CLAUDE.md's "buy M2" is stale) |
| M3 nylon standoffs | ULN2003 / driver mounts | few | 380pc kit (Tray 1) |, |
| Track hinge pins | Ø1.75 filament, Ø2.2 boundary bores only (2026-07-12 print-in-place strips: the 59 in-strip joints/side ride INTEGRAL printed Ø2.0 pins). Per pod: 3 strip-to-strip + 2 at the master (its far-end pin + the jaw closure pin) = **10 pins x ~46 mm** ≈ 0.5 m, cut from an owned spool (the black CR-PETG is tougher than PLA for pins) | 10 | spooled (Tray 1) |, |
| Ø4 dowel pins | body-to-pod join (2 per side), Ø4x12: modeled (wall slip holes + rail press sockets) | 4 | 0 | **4** |
| HC-SR04 ultrasonic | x4: forward + REAR obstacle (front/rear walls, inside the twin grille rings) + front/rear cliff (flush in the deck slopes, boards behind the 5-thick skin). **Inventory has ZERO** (checked 2026-07-10) | 4 | 0 | **4** |
| M4x40 + nuts | road-wheel bolt-axles (head = outer hubcap, shank in Ø4.2 wheel bore, nut captive in the beam slide-up slot). **HARD SHANK SPEC (2026-07-16 K1):** under-head length 40 mm; **plain journal 34.0..35.5 mm** (covers full 30.0 wheel hub + 1.0 beam-to-wheel gap + beam path to the nut outboard face at 33.95 under-head; thread must NOT enter the wheel bore; threaded tail must still engage the M4 nut with ≥2 turns of M4×0.7 = 1.4 mm). **REJECT** full-thread M4x40 kits (thread chews the Ø4.2 bore or clamps the wheel). **REJECT** stock DIN 931 / ISO 4014 M4x40 (nominal plain ~18..20 mm starts thread inside the wheel). **REJECT** Ø5 shoulder screws (wheel bore Ø4.2 and beam bore Ø4.4 cannot accept Ø5). **ACCEPT:** partially-threaded M4x40 with measured plain shank in 34.0..35.5 mm; or the printed `hw_m4_bolt` stand-in (JOURNAL_L=34.7 / THREAD_L=5.3) until metal arrives. M4 nuts OWNED | 10+10 | nuts: OWNED (the 600pc M2-M5 kit lists **M4 nuts x40**, settled 2026-07-13); bolts: 0 | **10x M4x40 per hard shank spec** |

### Printed parts (watertight; tank base + split head)

**Materials:** print `head_back` (all four pieces), `screen_tray` and `head_door` in
**PETG, not PLA**. The Pi 5 lives in the closed head and sustains 70-80 C bursts under
brain load (measured, see CLAUDE.md thermal notes); PLA creeps from ~60 C, so a PLA tray
would slowly sag under the screen+Pi module and a PLA back wall would relax its snap
tongues and tray pilots. The head_door shares the same hot bay, so it goes PETG too
(its snap tongues also live longer in PETG). Everything else on the robot -- chassis,
tracks, bezel, neck, pan parts, cosmetics -- can stay PLA. The black CR-PETG spool
(Tray 1) covers the PETG set.

- `chassis_lower_front` / `chassis_lower_rear`: the open-top tub, split at y=+26 for
  print speed; join with 2x M3x20 (axis Y, heads in the front pads, captive nuts rear)
  + 2x Ø4 dowels in the floor pads at x +-61; the deck and bolted side panels bridge it
- `chassis_deck_front` / `chassis_deck_center` / `chassis_deck_rear`: the pan deck in
  three plates (seams y 66/-52, half-laps + 2x M3 down through each strip into shelf
  pilots); the center carries the whole pan seat + its own 4 hold-downs; the corner
  hold-downs live in the strips
- `track_L` / `track_R`: tank track pods: 64 links/side (4 print-in-place strips +
  master; integral Ø2.0 pins in-strip, Ø1.75 filament pins at the 5 boundaries), 12T
  pin-pocket sprocket (real circular pin seats since 2026-07-10, r 1.15 on the 19.32
  pin circle), 2 end idlers on 2x F688ZZ each (30 wide; front tensions in its panel tower),
  TWO ground-run drive sprockets (spr_y rear + spr_y2 front; the front motor is
  OPTIONAL, all fittings modeled), 5 dished road wheels/side
  (30 wide) on M4x40 bolt-axles off the pod-rail wheel beams
- `pan_platform`: disc that yaws on the base (central shaft bore + off-axis cable pass)
- `pan_race` / `pan_balls` / `pan_retainer` / `pan_cage`: captured-BB lazy-Susan race, full-circle
  uplift retainer, and the BB spacer cage (18x 6 mm BBs; `pan_balls` is a placeholder for the bought
  BBs; the cage keeps them spaced so a turret lift doesn't scatter them)
- `neck_clevis`: rounded column + two cheeks that rise into the head and drive the tilt axle;
  vertical cable channel
- `head_bezel_L` / `head_bezel_R`: front frame split at x=+22 (M3 + Ø4 dowel in pads
  behind the forehead/chin strips); seam staggered off the back's for interlock
- `head_back_frame_L/R` + `head_back_panel_L/R`: rear cover in four (frames = walls +
  pivot hubs, print front-down, no ceiling support; panels = the flat 4mm back wall,
  print lying flat). 6x M3 from the back join panel to frame rim tabs; the frame
  halves share the top-wall flange (2x M3) and the panel halves a tongue/groove
- `screen_tray`: bench-mounted module carrier (2 rails + spine): the screen+Pi bolts to it
  on the bench (4x M3x10 into the factory bosses, open access), the loaded tray drops into
  head_back, 4x M3x10 drive from OUTSIDE the back wall (visible, between door and frame)
- `cam_cover`: camera board cover and cable trap
- `sd_plug`: friction plug for the microSD service slot (left wall + trim_rail_L); pull it,
  reach the card with straight forceps down the eject axis (~61 mm, sight line clear)
- `tilt_carrier`: removable tilt-motor cartridge plate; the motor's ears drop onto its
  pin-topped D-posts on the bench (2026-07-16 sandwich retention, see step C),
  4x M3x16 clamp it to the neck bracket from the open rear bay
- `track_keeper_L/R`: master-link keeper bars (2 bars + side tabs per pod, 1x M2 each);
  the master link body prints as link 0 inside each `track_L/R`
- `worm_wheel` / `tilt_worm`: real generated teeth (docs/WORM.md); the wheel has a round
  Ø5.2 bore and an accessible radial O2.5 pilot for its M3x4 tip-on-flat drive grub
- Cosmetic / design-ref set (render-only today, print with the head): side rails, forehead
  `led_strip`, `camera_pod` eye shell, rear `trim_hatch_frame`, chassis
  `trim_fascia` + `trim_rear`, and the placeholder gripper arms (mechanism TBD)

### Plastic hardware stand-ins (interim, plate "Hardware stand-ins")

Until the metal order lands, every buy-list hardware row above has a PRINTED
stand-in (`src/standins/` -> `stl/hardware/`), so the whole robot dry-assembles in
plastic. The BOM is unchanged; swap each stand-in 1:1 for metal on arrival.

**REWORKED 2026-07-16** ("as functional and as close to reality as possible"). The
M4 and M8 pairs now carry **real ISO threads** (`src/threads.py`) and screw together
for real. More importantly, the rework caught **three v1 parts that were physically
unbuildable** -- each had inherited nominal metal dimensions with no print
compensation, which looks perfect in CAD:

> **RULE: a stand-in mates PRINTED-TO-PRINTED or PRINTED-TO-STEEL, never
> nominal-to-nominal.** Budget 0.1-0.2 mm per printed surface, put the compliance on
> the printed part (crush ribs beat a tight window), and probe the real mating
> geometry -- never copy the metal part's numbers or the CAD placeholder's.

| Stand-in | Qty | Replaces | Notes |
|---|---|---|---|
| `hw_m4_bolt` | 10 | M4x40 bolt-axles | real SHOULDER bolt: plain Ø3.9 journal **34.7 mm** + M4x1.0 threaded tail **5.3 mm** (verified 2026-07-16 K1 against the live stack: wheel 30.0 + gap 1.0 + beam-to-nut-outboard 33.95 under-head; purchase window plain 34.0..35.5). The shoulder is the axial stop, so the wheel stays free however hard it is done up. Ø10.4 thumb head. **Stock DIN 931 M4x40 is REJECTED** (~20 plain starts thread inside the wheel); full-thread kits and Ø5 shoulder screws also rejected (see BOM row) |
| `hw_m4_nut` | 10 | (owned steel M4 nuts) | AF7 hex, real M4x1.0 internal thread + lead-in per face. AF and 3.2 thickness are the SLOT's (it is cut for an AF7 hex ACROSS CORNERS -- that is what centres it on the bore) |
| `hw_m8_bolt` | 4 | M8x70 end bolt-axles | knurled Ø22 thumb head, smooth Ø8.0 journal under the bushings AND through the tension slot, M8x1.25 thread only where the nut runs |
| `hw_m8_nut` | 8 | 4 inner M8 nuts + 4 outer jam nuts | AF13, real M8x1.25 thread, 6.0 tall + countersinks. The pair clamps each tower; no NYLOC analogue exists in PLA, so re-snug after creep |
| `hw_m8_washer` | 4 | Ø14.4 washers | **flatted to AF13**: a round Ø14.4 disc overlaps the tower nut cage by 5.2 mm³ (its old seat was deleted by running-gear v2). A printed wave washer was rejected -- it creeps by the mechanism it would compensate |
| `hw_f688_bushing` | 8 | F688ZZ bearings | **v1 could not spin** (all three fits closed nominal-to-nominal). Now bore Ø8.6, body Ø15.2 + its own crush ribs at Ø16.0, flange Ø17.9, 3 axial grease grooves. **Grease is required -- it is the service life, not a nicety** |
| `hw_pan_ring` | 20 | 18x Ø6 BBs | **v1 could not move** -- the torus slid at ~96 mNm vs the pan's ~15-17 mNm. Now 18 barrel rollers + 2 spares: Ø5.9 sphere, flats on the SPIN POLES, printed axis-up / installed axis-radial. **pan_cage is used again.** Print at 0.1 mm layers |
| `hw_tilt_axle` | 1 | Ø5 silver-steel rod | **v1 could not be assembled** (Ø5.000 into a Ø5.000 STEEL 695 bore = +0.000). Now Ø4.8 print-compensated with a center-only flat; both bearing journals stay round |
| `hw_seam_dowel` | 5 | Ø4x12 dowels | Ø3.9 (not Ø4.0 -- a printed dowel is the other half of the tolerance stack) + lead-in chamfers |
| `hw_foot_pin` | 2 | Ø3x8 trim_neckfoot pins | **Ø3x8, not x6** -- the 2026-07-15 socket deepening (5.0 socket + 3.0 collar = flush) |

Limits to respect on plastic (full rationale in `src/standins/__init__.py`):

- **The track tensioner now has a real clamp stack:** outer jam nut, tower, washer,
  inner nut. The idler stays free on the smooth journal while the tower is clamped.
- **M4 is a real fastener now**: it screws, tightens and re-uses. Snug it; don't lean
  on it (~400 N strip vs a metal M4's ~2 kN).
- PLA creeps, so preload decays over hours -- but with real threads that decay is
  bounded and recoverable: re-snug, nothing degrades permanently.
- Tilt homing is **usable** (~1.3-1.5 deg wind-up, and stall homing calibrates it out).
  Grub-on-flat backlash remains bench-only. Park at the balance point --
  the real cost is 1-3 deg of creep droop over hours.
- The dry pan **slews, but slowly and near the limit**, and may need a nudge from
  rest. Grease both grooves. Don't time the dry pan and call it a gear-ratio verdict.
- Idlers are greased plain bearings: ~50x a ball bearing's rolling resistance, but
  only 0.17-0.70 N to roll, which the track's own weight exceeds.

## Verify on arrival (caliper before printing)

The CAD models several bought parts from datasheet/typical dims, not measurements. The
rule for every row: **caliper the real part -> update the named param(s) -> `make build`
-> `make check` + `make fits` -> only then print the dependent parts.** Clone boards
vary: barrel/jack spacings tend to be stable across clones, mounting-hole patterns are
not. Printing a seat before its part has arrived is how reprints happen.

| Arriving part | Caliper this | CAD that depends on it (do not print first) |
|---|---|---|
| XL4015 5A buck | board LxW, mounting-hole pattern (40x20 assumed) + hole Ø, tallest component height | belly power tray posts (Ø6x6, Ø2.5 pilots, `build_belly_plate` in src/chassis.py); board must clear the z14 ballast ribs |
| MP1584 mini buck | board LxW only (zip-mounted, no holes) | zip-anchor pair spacing (x 20/34, y -58) on the belly plate |
| 12V PD trigger | board LxW, jack position + height above board, mounting-hole spread | rear-wall USB-C slot (14x8 at x -38, z0+24) + the 2x Ø1.7 M2 pilots at x -38±9 |
| HC-SR04 x4 | barrel c-c (26.0 assumed -- stable), barrel Ø (16.0/16.6 bores), board LxW, **mounting-hole positions (vary by clone!)** | front/rear grille recesses + fascia pilots; both cliff recesses in the deck slopes (1.2 skin-back recess + 4x Ø1.6 M2 pilots each, `sensor_cliff*`) |
| Gooseneck mic windscreen | foam Ø (17 assumed) + gooseneck stem Ø | ear grommet Ø15 compress-fit bores + Ø19/Ø15 trim rings in the head_back side walls (`ear_*` params) |
| LD2410 / SW-420 / TTP223 | board LxW + hole pattern each | chassis sensor seats (being added parametrized -- treat every one as VERIFY_ON_ARRIVAL, exact modules not yet chosen) |
| Sense HAT Rev2 (ordered 2026-07-14) | 65x56.5 outline, M2.5 holes on the 58x49 pattern, component heights | replaces the IMU posts + BME bosses on chassis_base with a 4-standoff HAT seat (next base iteration; the HAT covers IMU + temp/humidity/pressure, BME688 now optional-for-gas) |
| Joy-IT RPI5-HEATSINK5 (ordered 2026-07-14) | true installed envelope incl. fan | 65x45x15 EXCEEDS the verified official-cooler keep-out 63.5x42.5x13.7 -- re-run tools/probe_cooler.py with measured dims BEFORE head install |
| AI Camera IMX500 (ordered 2026-07-14) | module depth + lens barrel vs CM3 | forehead cam pod is CM3-sized; re-fit pass needed before swapping the eye |
| M8x70 + jam nut + NYLOC | nut across-flats (13.0 nom), nut height, washer OD, and usable thread span | panel-tower clamp stack + Ø14.4 flatted washer seat |
| M8 shank / Ø8 journals | actual shank Ø | tower Ø8.4 through holes + F688 8 mm bores (a fat zinc bolt binds) |
| F688ZZ | flange Ø (18) + width (5) + OD (16) | idler Ø15.95 press seats + Ø18.5x1.0 flange recesses |
| Narrow LED strip | strip width + dot pitch | 42x5x1.5 `led_slot` + the 36x2.5 front lip (widen `led_slot` to ~54x11 only if forced onto 8x5050 sticks) |
| Ø5 rod | actual Ø (silver steel is -0/-0.01; generic rod varies) | 695-2RS 5 mm bore slip fit, head clamp bores, and the 4.0 across-flats filed datum |
| XH connectors | crimped-head width | 16x8 platform obround + neck channel passes (sized for a 5-pos XH head) |

## Assembly order (verified)

Task #28 insertion-path + torque-path audit (2026-07-07): a full install order EXISTS
end-to-end. Every step below was checked with swept-cylinder driver-line / extraction
probes on the neutral-pose mesh; the numbers in parentheses are the worst measured
clearance. Read the **order constraints** and **nasty steps** at the bottom before you
start: several joints are only reachable at ONE point in the sequence.

Tools you need: a **1.5 mm hex key** (head-clamp grubs), a standard M3/M2 driver, tweezers,
and thread-lock or CA glue (cosmetics). (The old ~95 mm slim driver is retired: the screen
tray killed the 88.5 mm blind channels, 2026-07-08.)

### Sub-assemblies to build on the bench FIRST (they become unreachable once seated)

- **A. Neck + pan platform.** With `pan_platform` upside-down on the bench, drop 3× M3 up
  through its underside Ø6.5 counterbores (r16.5 circle, clocked 270/30/150) into the
  `neck_clevis` base pilots. The counterbores face DOWN into the race once seated, so this
  bolt-up is impossible after the platform is on the balls. Torque path: screws clamp
  neck to platform; the platform's integral 16T pinion takes the drive from the pan
  motor's 32T gear (fast-pan 2:1 gear-up 2026-07-12; the old on-axis D-bore is gone).
- **B. Tilt axle prep.** File the center-only flat on the Ø5 rod (span and depth in the
  BOM row above) and verify it with the axle flat + wheel grub coupon below. The wheel and
  its spacer tubes are NOT mounted on the bench: a mid-span wheel cannot pass a 695 bore,
  so they thread onto the axle inside the clevis gap at step 10. The tip-on-flat contact
  is the positive torque path; the threads hold preload.
- **C. Tilt-motor cartridge.** Drop the tilt 28BYJ onto `tilt_carrier`: the can passes the
  plate's Ø29.1 bore and each ear hole lands on a Ø3.8 pin atop the plate's D-posts
  (2026-07-16: the real motor is 9 mm shorter than the old placeholder modeled, leaving
  only 0.2 mm in front of the ears -- the old 2x M4 ear bolts are geometrically impossible
  and are GONE from the BOM). Press the worm onto the D-shaft. Clock the O2.5 radial
  pilot over either D-flat, fit the M3x3 cup-point grub, and seat it gently with its tip
  on the flat. This is low-load axial retention, not a structural clamp. The grub stays
  in the worm and travels with the cartridge during rearward extraction. Hold the motor against the
  posts while inserting (step 11); driving the carrier's 4x M3x16 captures the ear bar
  between the post fronts and the neck's pocket-front wall (0.25 mm float, pins lock
  rotation). It comes OUT the same way for a motor swap, no head teardown.

### Chassis + drive (fixed frame)

> **ACTION BEFORE ORDERING:** Measure all 3 Bag-5 TT 1:120 shaft tips now. Record
> whether each has the Ø2 axial hole. Order M2x25 screws and Ø9 washers only for
> motors that actually have it. Many TT variants omit this hole.

1. **Print + prep the chassis.** Confirm the deck pan-seat, the pedestal, and both TT
   motor pockets are clean.
2. **Fit the four structural side panels.** The old separate `pod_rail_L/R` parts and their
   dowel joint are retired. Each panel carries its wheel beam and end tower as one print.
   Seat the front/rear splice tongue and locating pads, install its two M3 screws into
   captive nuts, then bolt the panel feet to the lower tub. The tongue and separated feet
   hold alignment before tightening.
   Before fitting the track, slide two M3 nuts into each shoe trap and press the matching
   `track_shoe_{L,R}_{rear,front}` upward onto its two locator pins at y=-68 or +90.
   Drive two M3×10 countersunk screws from below. The shoe is 10.6 mm wide in X,
   14.76 mm along Y and 4.6 mm thick, with its running face at z=10.4. Fit all four
   shoes for a twin drive; the +90 front pair may be omitted with the optional motors.
3. **TT motors.** Set each TT gearmotor: shaft +X into the sprocket hub's double-D socket,
   front tab into the rear-wall pocket, nub into the wall pocket, 2× M3 through the
   gearbox + wall. Push each upper nut past the slot-mouth crush nibs until it clicks
   into the captive seat; it stays retained while the motor is positioned.
   The M2x25 plus Ø9 washer is the preferred axial retainer only when the measured
   shaft has the Ø2 tip hole. Otherwise use the positive cross-pin fallback:

   1. Slide the sprocket fully onto the shaft and mark the shaft through the vertical
      Ø2.1 hub bore.
   2. Pull the sprocket off and file an approximately 1 mm deep notch across the round
      shaft arc at the mark. Do not cut through the plastic shaft.
   3. Reassemble and drop a straight Ø2 filament pin through the upper hub wall, the
      filed shaft notch, and the lower hub wall.
   4. Trim both ends flush with the Ø12 hub. The pin must never stand proud of the hub
      OD because the hub slides through the side-panel journal.
   5. Secure the upper pin end against vibration walk-out with a small drop of CA in
      the bore mouth, or briefly heat-mushroom it with the iron tip, still sub-flush.
      The bore is open-top in service, so an unsecured pin can migrate up and out.

   The pin positively locks axial motion and torque. The socket crush ribs are only a
   handling aid. Service the pin from above with the track open.
4. **Track running gear.** Press an F688ZZ into EACH face of all four end idlers (Ø15.95
   seat + Ø18.5 flange recess both sides). Each end wheel: M8 bolt from outboard
   through the bearings, add the OUTBOARD jam nut against the tower, then the flatted
   washer + NYLOC nut inboard, started ON THE
   BENCH with the deck upside down. Orient each nut HEX FLATS FORE-AFT: as the deck
   drops onto the tub the nut descends into its prow-cheek NUT CHANNEL (y-walls 13.8
   apart), which grips the flats -- all torquing happens from the outboard head, no
   inboard tool ever needed. Before fitting each front NYLOC, deburr and press one
   12x28x1.0 steel strip fully flush into the tower's x62 bearing-face recess. Its
   square ends must seat against both printed end shoulders. Rear pair: snug. Front
   pair: leave loose, set tension
   AFTER threading the tracks, then tighten from the head -- the channel holds the
   nut, the nut clamps the slot. Fit the sprockets on the
   TT shafts (they mesh the ground run under the hull; the robot's weight seats them). Push an M4 nut up each wheel-beam slot until it clicks past the two crush nibs. The nuts remain retained while the panel is handled; inserting them on the bench is convenient but not required. Then bolt each road wheel with its M4x40 from outboard --
   snug, then back off 1/8 turn so the wheel spins free.

   Each side-panel beam now closes around the Ø12 sprocket hub over the absolute
   |X|=70.2..74.5 band with a Ø12.5 full-circle printed journal. Apply a thin film of
   plastic-safe grease to the hub before insertion and renew it when the track is open.
   The remaining |X|=74.5..81.2 crossing is open on top for cross-pin access. The owned
   MR105 bearing cannot replace this land: its 5x10x4 bore is too small for the Ø12 hub,
   while the hub itself contains a Ø6 free bore, so there is no compatible race seat.
5. **Join the strips + close with the master (print-in-place chain, 2026-07-12).**
   Each pod is 4 PRINT-IN-PLACE strips (16+16+16+15 links, hinges already free off
   the printer -- flex every joint once to crack any sag bonds) + 1 separate master.
   On the bench: pin the strips end-to-end with 3 Ø1.75 filament pins (each boundary
   = one strip's Ø2.2 open A-bores interleaving the previous strip's Ø2.2 far bores),
   then pin the MASTER's far end to strip 1's first link (4th filament pin). Wrap the
   open chain around the pod with the front idler retracted. Seat the last filament
   pin (5th) in strip 4's final-link far bores, swing the master's open jaws down
   onto it, slide the two `track_keeper` bars into the jaw slot from the side faces,
   and lock each with its M2 into the side-face pilot. Tension the idler -- run the
   chain TENSIONED: the PIP joints carry 0.35 radial slop (~8 mm of loop slack vs
   the old filament chain) that otherwise lands as top-run sag; if the front
   tension slot runs out of travel on the physical chain, that is the expected
   first fix (more slot travel), not a link redesign. Track removal forever after:
   2 M2s out, slide the keepers, lift the master off its pin.

### Pan joint

6. **Pan motor + drivers.** Fit the printed 32T `pan_gears` onto the motor's D-flats, then
   drop the pan 28BYJ into the pedestal can pocket (fast-pan 2026-07-12: the shaft sits
   OFF-axis at (-19.2, 0), gear up; ears run along X), clamp the 2 ears with M3 into the
   pedestal pilots from ABOVE (deck open). Mount ULN #1 and the 2nd ULN/MX1588 board on
   their standoffs; wiring box leads exit the pedestal +Y relief.
7. **Power tray, ballast, then belly plate.** Screw the PD trigger to the rear-wall M2
   pilots (jack aligned with the USB slot), the 5A buck to the belly plate's 40×20 post
   grid, zip the mini buck beside it, and wire per firmware/WIRING.md (leave 60 mm slack
   on every tray run; zip the incoming wall cable to the floor anchors as strain relief).
   Fit `chassis_pedestal` to the loose belly plate with its two printed pins near
   mid-slot and start the four M3x12 csk screws into the captive pedestal nuts.
   Leave them loose enough for X adjustment. The swept countersinks keep every
   screw flush anywhere in the slot instead of pulling the pedestal back to nominal.
   **Backlash setting:** mesh the 32T motor gear against the platform's 16T pinion
   with a 0.10 to 0.15 mm paper feeler between the flanks. Snug all four pedestal
   screws, remove the feeler, then rotate the platform one full turn by hand and
   check for tight spots. Re-set if it binds. The target is perceptible but small
   lash at the teeth.
   Load the low ballast into the rear bay + the belly-plate pockets from BELOW, then bolt
   on `belly_plate` (6× M3 csk, flush at z=7). Ballast must go in before the plate closes
   the floor.
8. **Pan race.** Grease the `pan_race` lower groove, seat it on the deck floor, lay the
   `pan_cage` ring over it, and drop the **18× 6 mm BBs** through the cage pockets into
   the groove with tweezers. The cage keeps them spaced; any later turret lift leaves all
   18 sitting evenly in the groove instead of bunching and rolling out. Load all six
   retainer nuts through the inward-opening seat-wall slots before seating the race,
   since the platform and retainer close that access.
9. **Lower sub-assembly A** (neck+platform) onto the BBs so the platform's upper groove
   captures them and its integral 16T pinion drops into mesh with the motor's 32T gear
   (fast-pan 2026-07-12: fit the 32T on the motor D-flats BEFORE this step). Screw
   drop `pan_retainer` straight down over the seated platform. Its 90.8 mm lip ID clears
   the platform's 90.0 mm top-band OD throughout the insertion path. Seat all six lobes
   in their deck pockets and drive 6x M3x10 into the captive nuts. The continuous lip
   reaches over the platform rim rebate to hold the top-heavy head down. Check the
   platform spins free.

   **Printed race acceptance** (do this after the head is fitted, step 12+, so the race
   sees the real top-heavy load). Bench physics, not CAD: ~8 N/ball Hertz on PLA
   cold-flows and abrades; the 0.2 mm groove clearance sits inside FDM scatter, so a
   given print may rattle or pinch and will worsen with wear. The post-gear-up torque
   budget is ~15 mNm at the platform vs ~7 mNm assumed race friction (little headroom).

   - **Measure breakaway torque:** push sideways at a known lever (e.g. a kitchen gram
     scale against the head side at a measured radius from the pan axis). Torque =
     force × radius. Example: 10 gf at a 100 mm lever ≈ 10 mNm.
   - **ACCEPT** at <= 10 mNm breakaway.
   - **REJECT** above 10 mNm, or if the platform rattles axially more than perceptibly,
     or if breakaway grows noticeably after a few hundred sweeps. Then fit the
     commercial ring (BOM "Bearings, race, axles"; print-3 option below).
   - **Derate (between accept and upgrade):** at 7-10 mNm of friction the pan still
     slews but acceleration roughly halves (net accel torque 15 - 10 = 5 mNm vs the
     budgeted ~8); a 180 deg sweep stretches from about 2 s toward 3 s. Below ~5 mNm
     friction, nothing changes vs budget. Above ~12 mNm, stall-homing detection gets
     unreliable and the commercial-ring upgrade is mandatory (do not ship on the
     printed race).
   - **Upgrade path (print-3, NOT modeled now):** fitting the commercial ring means
     re-cutting the deck seat and the platform underside for the ring's races (a
     variant of `chassis_deck_center` and `pan_platform`). Frozen shells stay clean
     (separate-by-stability rule); model against the bearing actually bought, dims
     VERIFY_ON_ARRIVAL. Until then the printed race + BBs is the default path.

### Tilt joint + head (all on the pan group)

10. **Bearings + axle cartridge.** Press a 695-2RS into each neck cheek from the clevis gap
    (seats open flush to the inner face; a light lead-in helps start the press). Insert
    the prepped axle (B) through one cheek bearing, thread the `worm_wheel` and its two
    spacer tubes onto the leading end inside the gap (wheel meshes the worm), then drive
    the axle on into the far bearing. The round wheel bore and tubes pass freely over the
    round journals. With the
    head not yet hung, use the open rear bay to center the wheel, clock the filed flat to the
    -Y hub pilot, and seat the M3x4 grub flush. Loosen this grub before pulling the axle.
11. **Insert the tilt cartridge.** Slide sub-assembly C (carrier + motor + worm) in from
    the open rear bay: the worm passes the bracket plate's Ø12.2 bore, its tail lands in
    the open-top cradle groove, the can registers in the Ø29 pocket, the motor's ear bar
    rides the neck's ear-bar channel to 0.2 behind the pocket-front wall, and the
    carrier's 4 bosses land on the plate/column rear faces. Drive 4× M3×16 from the rear
    into the captive nuts in the neck blocks -- this also captures the ear bar between
    the carrier's D-posts and the neck wall (hold the motor against its pins until the
    first screws bite). (Extraction reverses this and is UNCONDITIONAL since the 2026-07-12
    3-start worm: the mesh back-drives, so with a dead motor just hand-nod the head while
    pulling and the worm screws itself out. The old rule -- drive the head fully UP first
    because the single-start pull needed ~46° of nod against ~34° of stop travel -- is
    retired, 2026-07-13.) Route
    the tilt ULN wiring on the column back standoffs, board centered at z 93, below the
    carrier (motor + driver both ride the pan group, so no leads cross a joint).
12. **Hang the head on the axle.** Before lowering `head_back`, push each M3 clamp nut
    through its downward-facing slot mouth until it clicks past the crush nibs and seats
    on the cross-bolt axis. The front-down bench pose is still convenient, but retention
    no longer depends on it. Lower the head so its side hubs take the axle ends, then drive
    the two M3 pinch-clamp bolts from the rear bay. The axle now turns with the head; the worm holds tilt with the
    driver off ONLY marginally (fast-tilt 2026-07-12: the 3-start worm back-drives;
    hold is 28BYJ detent+gear friction through 4:1 -- firmware energize-hold or park
    at the balance point; see CLAUDE.md fast pan/tilt pass).
13. **Screen + Pi module (tray).** On the BENCH: bolt `screen_tray` to the combined
    touchscreen+Pi with 4× M3×10 pan heads straight into the display's factory 126.2×65.65
    bosses (the pillars are z-offset from the bores, so the driver line is open). Power-test
    the module on the desk if you like -- it is now a self-contained unit. Then drop the
    loaded tray into `head_back` from the open front (the pillars pass z-clear of the clamp
    tubes) and drive 4× M3×10 from OUTSIDE the back wall into the pillar-end pilots: short,
    visible screws in the fixed strip between the door outline and the hatch-frame opening.
    The bezel pocket locates the glass when the head closes (step 15).
14. **Camera + forehead LED.** Mount the CM3 front-face-in on the 4× M2 pier bosses, trap it
    with `cam_cover` (2× M2 + ribbon pinch), drop the CSI ribbon into the pocket. Seat the
    WS2812 forehead segment in its recess and route the 3 wires through the wire pass to the
    Pi. Route the Pi power pair per the cable step below.
15. **Close the head.** Bezel to back: 8× M3×35 through the perimeter posts into the captive
    nuts in the back bosses (screws from the front). Fit the rear service `head_door`
    (the stepped rear pod): engage the two top hook tabs first, swing the door in until
    both leg snap tongues CLICK behind the wall band beside the void (tool-free; replaced
    the 2× M3 csk 2026-07-10). To open: firm pull on the pod's bottom edge (35 mm proud,
    that IS the grip); the barbs' back ramps cam the tongues inboard and release.

    **SERVICE (door / dead head):** the tilt drivetrain occupies the pod cavity at the
    ±33.8° stalls by design (hollow clearance, not a closed-door clash). `tools/probe_door_stall.py`
    (2026-07-16) swept the tool-free open path (hook pivot 0..24°, then 15 mm lift along
    swung -Y) at tilt -33.8 / 0 / +33.8 against `tilt_carrier`, `motor_tilt`, `tilt_worm`,
    `worm_wheel`, and `neck_clevis`: **all three poses path-clear** on the baseline cavity
    (no enlargement). Stall-open is therefore geometrically possible, but the margin is
    millimeter-scale (closed-pose drivetrain-to-door clearance is ~2-3 mm at the stalls,
    and the swept path was checked at 2 deg / 1 mm resolution); **neutral tilt remains
    the comfortable service pose** (more free volume, easier hands, print tolerance and
    an un-held nodding head both eat into that margin). For a dead-motor or
    dead-Pi head: the 3-start worm **back-drives**, so hand-nod the head to roughly neutral
    first, then either hold it there with a second hand or wedge a soft prop (folded cloth /
    foam block) between the head chin and the chassis deck before pulling the door. Why prop:
    without energize-hold the head can slowly nod under its own imbalance while you work, and
    a hard-down park is awkward even though the open path does not collide.

15b. **Antenna drives.** Push one metric O-ring 6.0 x 1.0 into each modeled top-wall
    gland, then drop each
    mast in from above (rack facing the pinion slot), then hang `ant_bracket` on the back
    wall (spine + locating shoulders and 4x M3). Insert each printed `ant_output_*`
    half-shaft/pinion through its Ø4.2 bushings, fit `ant_idler_axle_*` and the compound
    `ant_idler_gear_*`, press `ant_motor_gear_*` onto the motor double-D, and bolt each 28BYJ nose-through
    its face plate (2x M3 into the vertical-ear pilots, shaft inboard). Each mast has its
    OWN motor + ULN2003 (independent control); wire both to the Pi in the head. Homing:
    leave park at the lowest step rate for maximum torque, then ramp. BUY: 2x metric
    O-ring 6.0 x 1.0, NBR or silicone; silicone is preferred for low breakaway.
    All 30T/12T/27T m0.8 gears, axles, shafts, and rack teeth are exported printable parts.

    **BENCH BREAKAWAY PROTOCOL:** assemble one mast and ring with NO gears fitted. Measure
    axial breakaway with a 0-1 N spring gauge, or hang calibrated 10/20/30 g weights from
    the mast tip. Sliding breakaway target: <=0.15 N (~15 g). Park-groove breakaway target:
    0.2-0.3 N (20-30 g). If outside the window, silicone grease lowers sliding friction;
    a 6.0 x 0.8 ring gives a lighter section/squeeze variant; or reprint the cheap vertical
    mast with `ant_park_groove_depth` adjusted by +/-0.1 mm. Groove depth is the park-force
    tuning knob. Final friction and breakaway are bench validation. CAD fixes only the
    geometry and the acceptable window.

### Cables (per docs/CABLE-CHECK.md + firmware/WIRING.md)

16. Wall PD brick → rear PD trigger (12 V) → belly tray bucks. The Pi-rail pair (18 AWG,
    from the 5A buck) coils a **2-turn service loop (~600 mm) at r≈48, z≈38–45** in the
    cavity → 16×8 deck pass → platform slot → neck channel → the column top-left exit
    window → through the bottom-rear head slot to the Pi's **GPIO 5V/GND pins** with
    **~60 mm of free head lead** for the tilt drape. Set `usb_max_current_enable=1` +
    EEPROM `PSU_MAX_CURRENT=5000` (GPIO power skips PD negotiation). Software-limit pan
    to ±90° (hard stops at ±93.3) so the loop never over-winds.

### Cosmetics LAST (glue + locating pins)

17. Press-and-glue the pin-located cosmetic parts: `trim_rail_L/R`, `trim_hatch_frame`
    (**after** the screen, its band overlaps the 4 driver-channel mouths, up to 2.3 mm),
    `camera_pod`, and the chassis `trim_fascia` / `trim_rear` / `sensor_rear`
    grille cap. Fit fascia electronics if used: HC-SR04P barrels through the Ø16 passes, amber
    corner lamps, front LED strip, rear buzzer/speaker.
18. **Final check + homing.** Power on; firmware stall-homes pan against its ±93.3° deck
    stops and tilt against its ±33.8° fin stops, backs off, and zeroes. Sweep pan ±90 and
    tilt ±30 and confirm the screen/Pi stack, worm, cheeks, axle, cables and bottom head
    edge stay clear (matches the `make check-sweep` gate).

### Order constraints (do NOT reorder)

- Body↔pod join + TT screws (step 3) **before** ULN #1 (step 6): the board blocks cavity access.
- Neck↔platform bolt-up (sub-assembly A) **before** seating on the balls, counterbores face down.
- Six retainer nuts **before** the race, cage, and BBs (step 8); race, cage, and BBs
  **before** the platform; platform **before** the drop-on retainer ring (step 9).
  Power tray + ballast (step 7) stay **before** the belly plate closes the floor.

### Nasty-but-possible steps (measured)

- **Head-clamp grubs (step 12):** 1.5 mm hex key driven blind UP through the motor bay,
  4.0 mm clearance. Kept deliberately: the grubs give continuous tilt-zero trim.

(2026-07-08 passes retired the old tilt-motor-ear reach, the inaccessible wheel grub, the
last-track-pin loop flex, and the 4× 88.5 mm blind screen-standoff screws -- the worst
step in the build is now four short bench screws plus four visible wall screws.)

### Squaring up: datum + shim procedure (first build)

The tilt axis and the screen optical plane sit at the end of a long printed stack
(chassis lower tub → z46 deck seam → pan race → pan platform → neck clevis → cheek
695 bearings → axle → head). CAD gates (`make check` / `fits` / `joints`) check part
PAIRS at nominal, not accumulated tolerance. A first physical build needs this
procedure to square itself up without reprinting anything.

Params cited below: `clevis_half`=22 (cheeks at x ±22), `tilt_axis_y`/`tilt_axis_z`
= -18 / 153, `scr_mount_pts` factory pattern 126.2 × 65.65, `base_h`=66 (deck pan-mount
plane), neck→platform 3× M3 on r16.5 clocked 270/30/150 about (0, `neck_y`=-17),
head-clamp grubs at x ±30, pan race 18 BBs on Ø80 (`pan_race_n` / `pan_race_circle_d`).

#### Master datum

**Master datum plane = the pan platform's top face as seated on the BB race.** The
deck's pan seat defines it (`base_h`=66). Nothing below the race is adjustable: the
stack under it is edge-bearing (side panels prop the deck), so its errors tilt the
whole turret together and the pan sweep averages them out. Errors that matter to the
eye are platform-to-screen. All squaring happens between the platform and the head.

#### What to measure

Bench method: calipers + a machinist square. No dial indicator assumed. Do (a) after
step 12 (head hung), (b)/(c) after step 13 (screen tray in), (d) anytime the race is
seated.

**a. Tilt-axis parallelism to the platform.** Hold the platform still. Measure from
the platform top face up to each exposed axle end (or the head clamp bosses at
x ±30). Difference over the ~60 mm span (clamp-to-clamp, or cheek-to-cheek at
`clevis_half` ±22) is the axis tilt. Target ≤ 0.3 mm (~0.3°).

**b. Screen upright / lean.** Stall-home tilt, command zero. Stand a square on the
deck (or platform) and measure the gap to the glass at the top and bottom bezel
edges. Difference over the ~66 mm vertical mount span (`scr_mount_pts` 65.65) is lean.

**c. Screen twist (rotation about Y).** Same square, gap to glass at the left and
right bezel edges at one height. Difference over the 126.2 mm horizontal mount span
is twist.

**d. Pan wobble sanity.** Pan slowly ±90 and watch the head top edge against a fixed
reference. Cyclic rise/fall means race/platform debris or an unseated BB, not a shim
case. Re-seat the 18 balls on the Ø80 groove (step 8) and recheck.

#### Where shims go

| Symptom | Correction | Notes |
| --- | --- | --- |
| Tilt-axis tilt (a) | Shim washers under one or two of the three neck-clevis feet (3× M3, r16.5, clocked 270/30/150 about (0, `neck_y`)) between clevis base and platform | **Only place to correct axis parallelism.** 695 rib seats self-center -- do not shim bearings. |
| Tilt zero offset (screen looks up/down at commanded zero) | NOT a shim case. Loosen the two x ±30 head-clamp grubs and rotate the head on the axle (continuous trim, step 12), or fix in firmware after stall homing | Grubs are the intended trim; see Nasty-but-possible above. |
| Screen lean / twist relative to the head shell (b, c) | Shim between the `screen_tray` pillar ends and the `head_back` wall at the 4 tray screws (step 13) | 0.1 mm there ≈ 0.09° over the 65.65 mm vertical spread, ≈ 0.05° over the 126.2 mm horizontal. |
| Any single point needs > 0.5 mm of shim | STOP. Warped or mis-seated print. Find it (usually the z46 deck seam or a panel foot) | Do not bury a bad stack in shims. |

**Clevis-foot clocking (which foot raises which side of the axis):**

- **270° foot** (rear, -Y from pan axis through `neck_y`): raises the rear of the
  clevis → lifts the rear side of the axle plane (axis pitch relative to platform).
- **30° foot** (+X, slightly +Y of the column): raises the right cheek → lifts the
  +X axle end.
- **150° foot** (-X, slightly +Y): raises the left cheek → lifts the -X axle end.

Shim the low side. Equal shims under 30°+150° raise the front of the clevis without
rolling the axis; rear alone does the opposite pitch.

#### Shim stock + order

- **Stock:** printed 0.1 / 0.2 / 0.4 mm shim washers (Ø7 × Ø3.2, print a strip of
  each), or aluminum foil layers (~0.02 mm each) for fine trim. M3 steel washers are
  0.5 mm and too coarse for anything but gross correction.
- **Order is load-bearing:**
  1. Square the tilt axis at the clevis feet **before** hanging the head (or re-hang
     after: step 12 grubs must come off to drop the head).
  2. Hang the head; set tilt zero at the x ±30 grubs (step 12).
  3. Screen-tray shims last (step 13).
  4. Re-run the stall-homing sweep after any shim change -- stop angles move with the
     stack (step 18).

The CAD gates verify pair fits at nominal; this procedure is where the accumulated
real-print tolerance gets taken out, and it is expected to be needed on a first build.

### Track coupon protocol (Track coupon plate -- print BEFORE any strip plate)

The Track coupon plate carries **two** 5-link print-in-place strips + 1 loose master
link + both keeper bars (~1 h sliced in PETG):

| Unit (exporter name) | PIP far-bore | Radial gap on Ø2.0 pin | Role |
|---|---|---|---|
| `track_coupon_strip_d2.7` | Ø2.7 (`track_bore_pip_d`) | 0.35 mm | Production geometry (matches the 64-link loop) |
| `track_coupon_strip_d2.56` | Ø2.56 (coupon-only) | 0.28 mm | Tighter-gap A/B wear candidate |

Each strip is open-A first link, 3 integral-pin mids, open-far last, keels on.
Production loop geometry, `tools/probe_track_pip.py`, and the long strip plates stay
on Ø2.7 only; the Ø2.56 strip exists solely on this coupon plate
(`stl/base/track_coupon_tight.stl`, written under `EXPORT=1`).

#### Static checks (both strips)

1. Every PIP hinge frees after break-in flexing -- no fused knuckles.
2. Hinge radial slop: pull the 5-link strip taut and measure total stretch vs 40.0
   nominal; that gives real per-joint slack. Scale ×59 and check it still fits the
   **6.5 mm** front idler outboard tension travel via `delta_L / 1.84`
   (dL/d(idler_y) on the raised loop). Accept if scaled stretch ≤ 6.5 × 1.84 ≈ 12.0 mm
   of full-loop elongation budget; reject if a single 5-link strip already exceeds
   ~1.0 mm total stretch after static break-in (that scales past the tension budget).
3. Ø2.0 integral pins unbroken after 20 full ±35 deg articulations.
4. Keel faces clean (no sag scars), grousers flat.
5. Ø2.2 boundary bores accept Ø1.75 filament.
6. Master jaw drops onto the end pin; keepers slide and seat; M2 insert pilots hold.

Any static fail: adjust `track_bore_pip_d` / `track_pin_print_d` and reprint the
COUPON, not a strip. Prefer the Ø2.56 strip only if it frees cleanly and beats the
Ø2.7 strip on the powered stage below; otherwise keep production at 2.7.

#### Powered coupon (deciding bench test for mid-drive reliability)

After both strips pass the static checks, run a **powered coupon** on the production
(Ø2.7) strip first; optionally repeat on the Ø2.56 strip for A/B wear data.

**Setup (concrete):**

1. Mount a real mid-drive sprocket (printed `drivewheels_*` sprocket) on a TT
   gearmotor shaft, fixed to a bench block so the sprocket axis is horizontal.
2. Pin the 5-link coupon into a short loop segment against the sprocket ground-run
   mesh (use Ø1.75 filament at the open ends, or clamp the strip as a weighted flat
   run over the sprocket with ≥200 g hanging on the free end so pins stay seated in
   the conjugate pockets). A hold-down shoe or a wooden block with a 0.9 mm gap over
   the link crowns is enough to keep the mesh from lifting.
3. Drive the TT through the chassis MX1588 (or a bench H-bridge) at the firmware
   **80% PWM cap** (never 100%: 27 W budget rule). Forward 60 s, reverse 60 s, then
   continuous forward for the break-in block.

**Break-in:** 30 minutes continuous at 80% PWM, or **5000 sprocket revolutions**,
whichever comes first. (At ~120:1 TT gearing and ~200 RPM motor free speed under
light load, 30 min is on the order of several thousand pin engagements; count revs
with a mark on the sprocket if you can.)

**Re-measure after break-in (same gauges as static):**

| Metric | Accept | Reject |
|---|---|---|
| Per-joint bore ovalization (major − minor of each PIP B bore) | ≤ 0.10 mm | > 0.15 mm on any joint (pins are hammering the bore oval) |
| 5-link strip free length stretch vs 40.0 nominal | ≤ 0.8 mm total | > 1.0 mm total (scales ×59 → > ~12 mm loop elongation, past the **6.5 mm** outboard tension travel via /1.84) |
| Skip / lift under reverse at mesh | no tooth skip | any skip (erodes the **2.14 mm** rigid-chain skip barrier measured by `tools/probe_track_pip.py`; shoes only leave 0.9 mm of lift room) |
| Integral pin integrity | no cracks | any pin crack or break (a broken pin scraps a whole 16-link production strip) |

**This powered coupon is the deciding bench test for mid-drive reliability** under
representative load and reverse mesh. Do not commit the 6.8 h strip plates until the
Ø2.7 strip passes. If Ø2.7 fails ovalization/elongation but Ø2.56 passes, consider
adopting 2.56 into production (update `track_bore_pip_d`, re-run probe + coupon) only
after a second powered coupon confirms it.

Mid-drive engagement is quantified, not assumed: the conjugate 14T mesh has contact
ratio CR 1.48 and the rigid-chain pitch-ratchet barrier from `tools/probe_track_pip.py`
is **2.14 mm**. Fixed road-wheel bolt-axles cap lift to about 0.1 mm at their stations;
each hold-down shoe caps the sprocket mesh window to 0.9 mm.

#### Links / strips / masters are CONSUMABLES

PIP hinges are fatigue/wear items: integral Ø2.0 pins hammer Ø2.7 bores oval, designed
slack grows past the ~8 mm tension budget, the 2.14 mm skip barrier erodes, and a
broken integral pin scraps a whole 16-link strip. **Expected wear life is unknown
until the powered coupon above has real numbers** (log hours and km of desk travel
when you have them).

**Replacement procedure:**

1. Open the master link: remove the 2 keeper M2 screws, slide the keeper bars out,
   swing the C-jaw off the closure pin.
2. Count links from the master along the loop to the damaged strip segment
   (production layout per side: strips of 16+16+16+15 + 1 master).
3. Drop out the worn strip at its two filament boundary pins (or cut a fused pin if a
   mid-strip pin failed), seat the spare strip, re-pin the boundaries with Ø1.75
   filament (press tip into the Ø1.6 step).
4. Re-close the master, refit keepers + M2s, re-tension the front M8 until the mesh
   bites without top-run flogging.

**Print one spare production strip per side with the first batch** (same PETG spool as
the loop; the 16-link size covers the three long segments; also keep one 15-link if
you can spare the plate). Masters and keepers are also consumables on the same
service path (2 M2s + jaw wear).

### Bearing-seat coupon protocol (print BEFORE neck_clevis and any wheel plate)

Print `hw_coupon_695` and `hw_coupon_f688` in the supplied orientations. Their five
steps are marked by 1..5 tick notches and ascend through 0.075 / 0.100 / 0.125 /
0.150 / 0.175 mm rib crowns. Press the REAL bearing into the steps in ascending
order. The correct step is the LOOSEST one where all of these are true:

1. Seating needs a firm thumb or arbor push, not a tap-in drop.
2. The seated outer race cannot be turned by finger torque.
3. The bearing cannot be pushed back out by thumb from behind.
4. There is no whitening or cracking at the rib roots.
5. For the 695 only, the bearing still spins freely after seating, proving its
   shields were not crushed.

One step looser will creep. If two adjacent steps pass, choose the looser one. Re-key
`brg695_rib_proud` or `idler_rib_proud` to the winning crown, run `make build` and
`make check`, and only then print `neck_clevis` or the wheel plates. Repeat this
protocol for every filament brand or material change. Results do not transfer between
spools.

### Axle flat + wheel grub coupon

Print the `worm_wheel`, or a short hub coupon with the same Ø11 outside diameter, round
Ø5.2 bore and radial Ø2.5 pilot. Also print a simple fork gauge with two open slots:
**4.1 mm GO** and **3.9 mm NO-GO**. This gauge is documented rather than exported as a
stand-in because adding a new export, plate entry and invariant is more than the roughly
40-line trivial-part threshold.

1. File a 9.5 mm long flat to 1.0 ±0.1 mm depth. The 4.1 GO slot passes over the
   across-flats dimension; the 3.9 NO-GO slot does not.
2. Slide the round hub over an untouched round journal and center its pilot over the flat.
3. Seat an M3x4 cup-point grub flush with the hub OD. Confirm its cup lands on the flat.
4. Hold the axle and reverse wheel torque by hand. Confirm no hub rock and record backlash feel.
5. Loosen the grub and confirm the hub again slides over both round journal sections.

Grub-on-flat backlash versus the retired chordal D-key is **bench-only**. If the coupon
rocks or slips, adjust `wheel_grub_pilot_d` or `axle_flat_depth`, then reprint the coupon.

### Tilt torque + holding bench coupon

Run this protocol on the complete physical head before choosing the production worm pair:

1. Measure residual imbalance about the axle with a spring scale at a measured lever
   arm at tilt 0, +15, -15, +30 and -30 deg. Record the worst value in mNm.
2. De-energize at +30, -30 and 0 deg. Watch each position for 10 minutes and record
   any nod or drift.
3. Slew under the real head load at full speed in both directions through the full
   -30 to +30 deg working range. Record stalls, missed steps or hesitation.
4. Energize-hold off balance for 10 minutes. Record coil current and motor temperature.

Decision rule: if worst imbalance exceeds about 50 mNm, any de-energized nod is not
acceptable to firmware parking, or the loaded slew stalls, swap to the committed
single-start fallback pair. It is a drop-in, see docs/WORM.md. A spring-ball neutral
detent on the wheel hub remains the print-3 option and is deliberately not modeled,
per the 2026-07-13 decision. Prove the need on the physical head first.

### Recommendations (bigger than this pass)

- Print the axle-flat + wheel-grub coupon above and bench-check tip seating, hub rock and
  reversal backlash before committing the filed axle.
- Print supports: the neck's tilt-stop posts no longer start mid-air. Each
  outboard half (|x| 25.5..32, behind the post rear face) has a printed bridge
  that fuses into the leg, so the on-its-back orientation (export R(X,90))
  lands that half on material instead of a slicer support scar on the homing
  face. Still paint a support enforcer over the head_back stop fins (55°
  overhangs feeding a ~0.9 mm homing margin; treat the first stall-home angle
  as calibration). Print the track keepers lying on their 13.3×1.9 bar face
  so the slot-critical 1.9 width is XY-accurate.
- **Tilt stop faces are sacrificial homing surfaces** (fin/post PLA-on-PLA at +-33.8°;
  fins crush-hardened 2026-07-16 to x-span |26.5..32|, 1.375x contact width; inboard
  0.5 running-clear of the cheek face). Home at reduced drive once per boot only (firmware/WIRING.md
  "Tilt homing + hold"). If home zero drifts after months of boots, inspect the fin
  faces and post tops. Escalation if bench wear is real: a replaceable stop-cap
  (printed slip-on pad) on each cheek post -- deliberately not modeled now; keep the
  post z-faces and the +-33.8° first-contact angle if you add one.
- Track gauge is still ~184 vs a 205-wide head (~10 mm overhang/side): widen the gauge or
  accept it (tracked elsewhere).
- If field-servicing the screen without un-gluing the hatch frame matters, notch the frame
  band clear of the 4 channel mouths.

## Wiring

**See firmware/WIRING.md** (2026-07-08; power review 2026-07-16) for the full
architecture: 15 V PD-trigger input from a 45-65 W brick (12 V = 27 W fallback),
dual-buck belly tray (5.1 V Pi rail + 5 V motor rail), hard current limiting (CC pot +
TT-branch polyfuse), the brownout test protocol, what crosses each joint, Pi 5
config flags, connector/labeling rules, and the buy-list delta. Short version: only the
Pi-rail pair crosses tilt; the pan loop carries that pair plus the thin motor-rail/signal
bundle; DSI and CSI ribbons never leave the head.

## Order now (by lead-time importance)

1. **8x F688ZZ flanged bearings** (8x16x5, flange Ø18): most specific part, slowest to source;
   the end-idler seats are modeled around them (2 per wheel x 4 since the mid-drive).
1b. **10x M4x40** road-wheel bolt-axles to the **hard shank spec**: under-head 40 mm,
    **plain journal 34.0..35.5 mm** measured with calipers before accepting the bag.
    REJECT full-thread kits and stock DIN 931 / ISO 4014 M4x40 (~20 mm plain). REJECT
    Ø5 shoulder screws (bores are Ø4.2 / Ø4.4). M4 nuts are owned. Until metal arrives,
    print `hw_m4_bolt` (JOURNAL_L=34.7).
    + **4x M8x70 + 4 jam nuts + 4 NYLOC nuts + 4 washers** (end bolt-axles; Bag 13
    has no M8).
2. **4x HC-SR04** (forward + rear obstacle + 2 cliff; zero owned; plain 5V is fine on the
   Arduino I/O plane). TT gearmotors are COVERED (own 3); buy 1 more only for the optional
   twin-drive 4th station.
3. **Power electronics** (firmware/WIRING.md, re-specced 2026-07-16): a 45-65W USB-C PD
   brick that advertises 15V (the official 27W is a 12V fallback with firmware
   co-scheduling load-bearing), 15V PD trigger, XL4015-class 5A buck (CC/CV variant),
   MP1584 mini buck, 2A-hold polyfuse (MF-R200 class) for the TT branch, JST-XH kit +
   crimper, 1 m 18 AWG silicone pair plus 24-26 AWG high-flex silicone for the pan-loop
   runs, inline blade-fuse holder (the 5A blade fuse itself is owned).
4. **1 m narrow addressable LED strip** (4–5 mm wide, SK6805-2427 / WS2812-2020, ≥160 LED/m),
   one purchase covers the forehead 8-LED segment and the front 7-dot strip. (Alternative:
   widen `led_slot` to ~54x11 and buy two common 8x5050 sticks.)
5. **Ø5 SOLID rod ~100 mm** (tilt axle; NOT tube) + **Ø4x12 dowels** for the remaining
   registered shell/seam joints. The retired body-to-pod rail joint no longer consumes four.
6. **6 mm airsoft BBs** (bag of 100+; need 18): cheap, everywhere.
7. Optional: **MAX98357A I2S amp** x1 (pairs with the owned 8Ω speaker), **amber LEDs** x2–5.

Every board/hardware item above lands in the "Verify on arrival" table -- caliper before
printing its seat.

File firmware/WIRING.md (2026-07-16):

# Wiring + power (single wall USB-C tether)

Decided 2026-07-08 (maintenance/wiring pass). Power-budget and harness review
findings W1/W2 applied 2026-07-16: default input is 15 V from a 45-65 W PD brick
with hardware current limits independent of firmware; the pan loop uses high-flex
silicone throughout, strain relief at both ends, and day-one I2C twist + pullups.
The robot is powered by ONE USB-C cable from a wall PD brick into the chassis rear
jack. Everything below follows from that.

## Why not 5 V straight through

Three reasons, any one of which is disqualifying:

1. **PD negotiation.** The Pi 5 only unlocks its full budget when it negotiates
   5.1 V / 5 A over the CC lines with the official 27 W brick. A 2-wire VBUS/GND run
   from a chassis jack to the head can't carry that conversation, and the design rule
   is that only round wires cross the pan/tilt joints (no USB-C cable up the neck).
2. **Droop.** 5 A over ~0.8 m round trip of 20 AWG plus 4 connector interfaces drops
   0.3-0.4 V. 5.1 minus 0.4 is brownout territory for a Pi 5 under display + camera
   load.
3. **Motor transients.** Two TT motors stall at 1.5 A+ each. On a shared 5 V rail
   every stall dip lands directly on the Pi.

## Architecture: 15 V in (default), buck down locally

```
wall 45-65 W USB-C PD brick
  └── chassis rear jack (USB-C breakout + PD TRIGGER set to 15 V)
        │  15 V @ up to ~3 A stays in the chassis (crosses NOTHING)
        ├── BUCK A (XL4015-class, 5 A, CC pot set to 5.0 A) -> 5.1 V "PI RAIL",
        │     trimmed to 5.25 V at the tray; 5 A blade fuse inline as fault backstop
        │     └── power pair up the neck -> head -> Pi 5 GPIO 5V/GND pins (both pairs)
        ├── BUCK B (MP1584-class mini) -> 5.0 V "MOTOR RAIL"
        │     ├── ULN2003 #1 (pan stepper, chassis)          [unfused; coil-limited]
        │     ├── ULN2003 #2 (tilt stepper, neck column; 5V rides the pan loop)
        │     ├── POLYFUSE 2 A hold / ~4 A trip (MF-R200 class)
        │     │     └── MX1588 VCC (TT track motors only)
        │     ├── chassis LEDs / HC-SR04P
        │     └── Sense HAT 5V pin (LED matrix; ~40 mA class, 2026-07-14)
        └── (common ground everywhere; star point at the tray)
```

- **PD trigger at 15 V (default):** fixed 12 V is OPTIONAL in the USB-PD spec; many
  generic 45/65 W bricks do not offer it, while PD power rules make **15 V / 3 A
  mandatory on a 45 W brick** (and 20 V / 3.25 A at 65 W). Both bucks accept 15 V
  (XL4015 input to 38 V, MP1584 to 28 V). At the ~34 W worst-case draw, 15 V means
  ~2.3 A on the input pair (the same power at 12 V would be ~2.9 A), with brick
  headroom to 3 A. Spec the wall brick at **45-65 W**.
- **12 V is FALLBACK only:** the official 27 W brick offers 12 V / 2.25 A. Run the
  trigger at 12 V only when stuck on that brick; under 27 W the old strict firmware
  co-scheduling rules become load-bearing again (see Budget + Firmware rules below).
  Prefer buying a 45 W+ brick that advertises 15 V rather than living on the fallback.
- **Buck A (Pi rail):** trimmed to 5.25 V at the tray so the head end sees ~5.1 V
  after the neck run. Only Pi + display + camera + head LEDs load this rail
  (~13-16 W worst case, inside the buck's 25 W envelope). The head cooler fan
  (Joy-IT / official) plugs into the Pi 5's own 4-pin fan header and is counted
  inside the Pi figure (<0.5 W). The Sense HAT's 3V3 sensors ride the Pi's 3V3
  regulator via the neck drop (tens of mA); its 5V LED matrix feeds from Buck B
  locally in the chassis (~40 mA class, 0.95 mA/LED design).
- **Buck B (motor rail):** steppers + TT + chassis accessories. A TT stall folds
  THIS buck's TT branch (polyfuse), not the Pi rail and not the brick. 28BYJ
  ~240 mA each energized, TT ~0.5 A cruise.
- **Budget (honest version, review 2026-07-16):** 45 W at the wall is ~40 W usable
  after ~90 % buck efficiency. Naive worst case now closes with margin:
  Pi rail ~16 W + dual TT stall ~15 W + steppers ~2.4 W + LEDs ~1 W ≈ **34.4 W**
  vs ~40 W usable. The 27 W brick (~24 W after conversion) cannot close that sum
  (Pi 16 + dual TT stall 15 already overshoots); that is why 45 W is the default
  and why hardware current limits (next section) bound the fault even if firmware
  misbehaves. On the 27 W fallback only, re-apply the old co-scheduling as
  load-bearing and never combine ordinary peaks.

## Hard current limiting (independent of firmware)

Principle: **the brick's own OCP must be the LAST limiter to act, never the first.**
A brick fold drops the shared input, which drops motor-rail hold current on the
back-drivable 3-start tilt worm while gravity still pulls the head. Hardware
bounds each rail so a stalled motor cannot fold the brick.

- **Buck A (Pi rail), XL4015 CC trimpot:** buy the CC/CV board variant (two
  trimpots); it has a constant-current limit.
  On the bench, BEFORE connecting the Pi, set the CC limit to **5.0 A**: short the
  output through a series ammeter into a dummy load (or a dead short for the few
  seconds the pot needs), turn the CC pot until the meter reads 5.0 A, then restore
  the CV pot to the 5.25 V trim. The 5 A blade fuse is the fault backstop; the CC
  limit is the working limiter (it folds first on overload, the fuse blows only on
  a real short or a failed CC pot).
- **Motor rail, TT branch polyfuse:** the MP1584 has NO CC limit. Put a **2 A hold /
  ~4 A trip** polyfuse (MF-R200 or similar) on the **TT / MX1588 branch only**,
  between Buck B 5 V and MX1588 VCC. A dual TT stall (3 A+ sustained) trips the
  polyfuse and self-recovers after cool-down instead of folding the shared brick.
  The 28BYJ steppers are inherently coil-limited (~240 mA each energized) and stay
  unfused on the motor rail.
- **Firmware rules stay, demoted to defense-in-depth:** still cap TT PWM at 80 %,
  still never drive both TTs hard while a stepper steps, still stall-home pan/tilt
  at boot with tracks idle. Those rules no longer carry the power budget; the 45 W
  brick + CC pot + polyfuse do. Keep them so ordinary motion stays well under the
  hardware ceilings and the polyfuse rarely trips in normal use.

## Pi 5 configuration (mandatory)

Powering via the GPIO 5V pins bypasses the Pi's PD front end, so it defaults to
600 mA USB current. Set both:

- `/boot/firmware/config.txt`: `usb_max_current_enable=1`
- EEPROM (`sudo rpi-eeprom-config -e`): `PSU_MAX_CURRENT=5000`

Put a 5 A blade fuse inline on the Pi-rail pair at the tray (GPIO power skips the
board's input protection). The fuse is secondary to the XL4015 CC limit above.

## What crosses each joint

| Joint | Wires | Notes |
|---|---|---|
| pan (service loop) | Pi-rail pair (18 AWG silicone) + 5V/GND motor-rail feed for ULN#2 + 4x tilt-stepper IN lines + **I2C drop: 3V3 + SDA + SCL (Sense HAT, 2026-07-14)** | 11 thin + 1 fat pair; ALL high-flex silicone; the 16x8 platform obround and neck channel pass a 5-pos JST-XH head, verified stage 4/6 |
| tilt (drape) | Pi-rail pair ONLY | ribbons (DSI/CSI) never leave the head |

Pan is software-limited to +-90 (hard stops at +-93.3), so the loop never over-winds.
The pan loop flexes over that range daily; PVC hookup wire work-hardens and breaks
at the exit radii -- high-flex silicone is mandatory on every joint-crossing
conductor (see Harness rules).

### Pan homing discipline

The deck posts and platform lug are PLA. Stall impact is cumulative and crushes the
faces, which drifts home zero. Treat the stops as soft plastic, not steel.

- **Home gently.** Run the pan stall at HALF the normal step rate and, if the ULN
  driver / firmware path allows it, at reduced coil current. The 28BYJ through the
  2:1 gear-up multiplies stall force at the stop (~17 mNm at the lug even before a
  hard current push).
- **Cap overtravel.** Command at most ~8 deg past the expected stop position before
  declaring the stall. Never an open-ended sweep into the post.
- **Back off immediately.** After contact, reverse 3.3 deg and call that +-90 (the
  hard stops sit at +-93.3; the software limit is the backed-off pose).
- **Home once per boot.** Do not re-home on every move. Re-home only after a detected
  step-loss event (lost steps, skipped homing lug, encoder/open-loop mismatch if you
  add one later).

## Signals: bundle now, I2C drop NOW (Sense HAT, 2026-07-14)

The Pi lives in the head; the drivers live below. Today: GPIO lines run down the
neck bundle (4 pan-ULN IN + 4 tilt-ULN IN + 2 MX1588 PWM + optional sonar pair).
That is ~10 thin wires in the pan loop -- ugly but passes, and it is zero extra
hardware.

**The Sense HAT Rev2 makes the I2C drop day-one, not an upgrade.** The HAT can NOT
stack on the Pi: the head has no volume above the board (the cooler keep-out owns
the component face at millimeter margins) and stacking would also block the cooler.
It mounts REMOTELY in the chassis on the equipment base (`chassis_base`), where its
IMU is exactly where the awareness plan wants one: rigid, near the pan axis, sensing
BASE motion unpolluted by head moves. Electrically the HAT is pure I2C (0x6a/0x1c
IMU, 0x5c pressure, 0x5f humidity, 0x29 color, 0x46 LED matrix + joystick), so the
drop is 3 thin wires added to the pan loop -- 3V3 + SDA + SCL (ground is already
common) -- plus a LOCAL 5V feed from Buck B for the LED matrix. Do NOT route a
40-pin ribbon down the neck; only round wires cross the joints.

**Bus integrity over the ~0.5 m run (DEFAULT from day one, not an escalation):**
clock I2C at **100 kHz**; twist **SDA with a ground return** and **SCL with a ground
return** (never SDA twisted with SCL); fit **2.2 kΩ pullups to 3V3 at the HAT end**
from day one; keep stubs short. Why default, not optional: ~0.5 m of loop wiring
plus connector transitions approaches the 400 pF bus limit and runs beside stepper
coils, so 100 kHz I2C is EMI-fragile without the twist and the stronger pullups.
The LTC4311-class bus extender is the escalation if the bus is still flaky after
that.

Upgrade path unchanged (when the ULN bundle annoys you): a Pico or PCA9685 in the
chassis on the power tray (stacks on the buck grid with 20 mm standoffs), riding
THE SAME I2C drop (or UART). Then the pan loop shrinks to: Pi-rail pair + 5V/GND +
3V3/SDA/SCL = 7 wires, and the tilt ULN's IN lines come from the chassis board
instead. Mind the address map above when adding devices; note TCS3400 squats 0x29
(collides with a VL53L1X ToF if one ever joins).

## Connectors and harness rules

- Every run that crosses a joint or leaves a board is a **keyed JST-XH** plug (the
  cable passes were sized for XH heads). No soldered runs across joints; a board
  swap is unplug-replug. Crimping needs an XH crimper -- buy one, it pays for
  itself the first time a 28BYJ dies.
- Label both ends of every run (flag labels): `PI-PWR`, `MOT-5V`, `PAN-ULN`,
  `TILT-ULN`, `TT-L`, `TT-R`, `LED-F`.
- 28BYJ phase order matters: the JST-XH keying already prevents reversal; keep the
  factory connector on the motor pigtail.
- **Wire gauges + insulation (all joint-crossing = high-flex silicone):** Pi-rail
  pair **18 AWG silicone**, high strand count; **15 V input 22 AWG** (silicone
  preferred); every pan-loop signal / motor-rail / ULN / I2C conductor **24-26 AWG
  SILICONE**, high strand count. PVC hookup wire work-hardens and breaks at the
  flex points of the ~2-turn pan service loop; do not use it for any joint-crossing
  run.
- **Pan-loop strain relief (both ends, doc-only, no new geometry):**
  - **Bottom end:** zip the loop bundle to the existing 2x Ø3.2 floor-rim zip
    anchors behind the belly opening (x +-6, y -68) so cyclic flex cannot reach the
    buck-tray terminations.
  - **Top end:** zip a stopper tie around the bundle immediately ABOVE the
    platform's 16x8 obround pass, sized so the tie cannot pass through the
    obround. The tie bears on the platform face as a knot; cyclic flexing then
    lives in the mid-loop coils, not at the pass edge.
  - At install, lightly knife-chamfer the printed pass edges so the silicone
    jacket does not frett on a sharp PLA corner.

## Mechanical seats (modeled 2026-07-08; coords refreshed 2026-07-13 against src/)

- **Rear jack + PD trigger:** 2x Ø1.7 M2 self-tap pilots flank the USB slot on the
  rear wall's interior face at **x -38 +-9, z0+24** (slot + pilots moved off wall
  center 2026-07-11, the rear HC-SR04 owns x 0; old "(x +-9, z 19)" is stale); the
  trigger's jack aligns with the slot through the rear-left prow-cheek corridor.
  Trigger default = **15 V** (see Architecture); 12 V only for the 27 W fallback.
- **Strain relief:** 2x Ø3.2 zip anchors through the floor rim behind the belly
  opening (x +-6, y -68). Zip the incoming wall cable BEFORE the jack: a yanked
  tether loads the tie, not the board. The same anchors also hold the pan-loop
  bundle bottom end (Harness rules above).
- **Power tray:** Buck A mounts on a 40x20 Ø2.5-pilot grid on the belly plate's
  rear bay; Buck B zip-ties to the 2x Ø3.2 anchors beside it (x 20/34, y -58).
  Dropping the belly plate (6x M3) drops the whole power stage for service --
  leave 60 mm of harness slack on every tray run. Buck A sits component-side-up on
  the posts, so with the plate bolted shut its trimpots face the closed chassis
  interior: ALL voltage AND CC adjustment happens with the plate dropped (see
  Bringup). The TT polyfuse lives on the tray in series with the MX1588 feed.
- **Driver mounts:** ULN#1 on the chassis standoffs at (38, 20); MX1588 on the
  `uln2_c` standoffs at **(0, 80)** (moved 2026-07-11, dual-drive pass; old (-38, 45)
  is stale); tilt ULN on the neck-column standoffs, board centered at z 93 (dropped
  from 110: the tilt_carrier occupies z 113..153 in the same y band; rides the pan
  frame).
- **Sense HAT seat (pending CAD, 2026-07-14):** goes on the removable
  `chassis_base` equipment base -- exactly the in-flux-mount case the base exists
  for. Next base iteration replaces the (14,-12) IMU posts with 4x M2.5 standoffs
  on the HAT's 58x49 pattern (65x56.5 outline), LED matrix + joystick facing UP
  under the deck (service = lift the deck). Measure the delivered board first
  (VERIFY_ON_ARRIVAL); reprint is one small flat plate.

## Tilt homing + hold (firmware rules)

The head's clamp-tube fins stall against the neck cheek posts at +-33.8 deg (hard
stops; PLA-on-PLA). Contact planes are the post z-faces and the fins' angular faces
-- the 2026-07-16 crush-harden only grew the contact AREA along X (fins |x| 26.5..32,
1.375x width; inboard 0.5 running-clear of the cheek face), not the first-contact angle. Treat
the stops as sacrificial homing surfaces, not as day-to-day travel limits.

Rules for the tilt axis (pan is analogous against its deck posts at +-93.3):

1. **Stall-home at reduced drive only.** Half-stepping (or the coarsest microstep
   that still self-starts), lowest reliable coil current, and <= half the normal
   step rate. Full-current full-speed rams crush the small PLA patches and the
   home zero drifts.
2. **Home once per boot, not per move.** After stall, back off ~2 deg and set
   zero there. Do not re-seek the hard stop on every motion.
3. **Software-limit travel to +-30 deg.** That leaves the ~3.8 deg gap to the
   hard stops so they are homing-only. Never run a full-speed trajectory into
   the posts.
4. **Hold / park.** The 3-start worm (PARAMS `worm_starts`=3) back-drives --
   its lead is about 23 deg, so there is no unpowered self-lock. ALWAYS
   energize-hold whenever the head sits off its balance point. Park at the
   balance point before long idle and before power-off. Detent plus gear friction
   gives only about 27-54 mNm at the axle, so an unpowered off-balance head may
   nod. If the docs/ASSEMBLY.md bench coupon fails its decision rule, the committed
   single-start pair in docs/WORM.md restores mechanical self-locking.
5. **Wear.** If home zero drifts over months, inspect the fin faces and the post
   tops on the bench. Escalation path: a replaceable stop-cap on the posts
   (print-3 option, deliberately not modeled now) -- see docs/ASSEMBLY.md.

## Bringup order (first power)

Do this in sequence; the trimpot access constraint above makes the order load-bearing.

1. **PD trigger alone:** plug the brick in and meter the trigger output BEFORE wiring
   anything downstream. Confirm **15 V** (default brick), not a 5/9/12/20 V
   misconfiguration. On the 27 W fallback only, confirm 12 V instead.
2. **Set Buck A with the Pi rail DISCONNECTED.** Belly plate dropped and hanging on
   its harness slack (trimpot face-up toward you), power up and trim to 5.25 V
   unloaded. Then set the CC pot to 5.0 A into a series-metered dummy load / short
   (see Hard current limiting). Never trim with the Pi attached; a slipped CV
   trimpot sweep can cross 6 V+.
3. **Verify under load:** put a ~2 A dummy load (power resistor or USB load tester on
   a spare pigtail) on Buck A and confirm it still reads >= 5.15 V at the tray.
   XL4015 clones vary; a board that droops here browns the Pi later under camera +
   display load.
4. **Set Buck B to 5.0 V** the same way, steppers and MX1588 unplugged. Confirm the
   TT polyfuse is in series with the MX1588 feed before motors go on.
5. **Only now connect the Pi-rail pair** (5 A fuse inline) and boot. Check
   `vcgencmd get_throttled` returns 0x0 with display + camera running.
6. **Motors last:** steppers first, then TTs, watching the rails on a meter during
   the first moves. Then bolt the belly plate shut.
7. **Brownout test (both rails instrumented):** leave meters on both rails at the
   tray (or a 2-ch scope), then in sequence: (a) single TT stall at 80 % PWM (grab
   the sprocket), (b) dual TT stall, (c) dual TT stall while the tilt stepper holds
   the head ~30 deg off balance. **PASS:** Pi rail never below 5.0 V at the tray;
   `vcgencmd get_throttled` stays 0x0 through all three; the polyfuse trips on the
   sustained dual stall and recovers after cool-down; the held tilt does not slip
   more than ~2 deg during any event. The tilt case exists because a motor-rail
   brownout drops hold torque on the back-drivable 3-start worm while gravity still
   pulls -- that is the failure the polyfuse and brick margin are there to prevent.

## Buy list delta

- **45-65 W USB-C PD brick** that advertises **15 V** (default). The official 27 W
  brick is fallback-only (12 V / 2.25 A, strict co-scheduling load-bearing again).
- **PD trigger board set to 15 V** (or solder-jumper type; keep 12 V as the
  documented fallback jumper position only).
- XL4015 5 A buck module, **the CC/CV variant with TWO trimpots** (the CV-only
  board has no current limit and cannot satisfy the hard-limiting rule); set the
  CC pot to 5.0 A on the bench.
- MP1584 mini buck.
- **Polyfuse 2 A hold / ~4 A trip (MF-R200 or similar)** on the TT / MX1588 branch.
- JST-XH kit + crimper.
- **High-flex silicone wire, high strand count:** 18 AWG pair (1 m red/black) for
  the Pi rail; 24-26 AWG silicone for every pan-loop signal / motor / I2C run
  (PVC banned on joint crossings).
- Inline blade-fuse holder (the 5 A blade fuse itself is owned -- ATC/ATO
  assortment, inventory re-audit 2026-07-13).
- 2.2 kΩ pullups x2 for the HAT-end I2C (day-one default).

The owned LM2596 / selectable-output bucks are 2-3 A class: not a Buck A
substitute, but a selectable-5V module can stand in for the MP1584 as Buck B.

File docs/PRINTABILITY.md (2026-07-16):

# Printability audit

Current audit for the exported Parviz parts, verified 2026-07-16 on a Bambu A1-class
256 × 256 mm bed with a 0.4 mm nozzle. Source geometry remains parametric; do not repair
STLs directly.

## Release verdict

- 74 canonical STL artifacts generated. All are watertight volumes.
- Intentional multi-body exports are limited to PIP track strips, wheel kits, the three
  pan clips, two keeper bars, and the track coupon pair (production Ø2.7 + tight Ø2.56).
- The Bambu project contains 148 printable bodies on 22 category-named plates.
- Every brim-grown footprint fits the 256 mm bed.
- Every plate was sliced independently by Bambu Studio CLI with `Success.`.
- All 66 gated printed part types meet the 0.8 mm percentile wall requirement or a
  documented tooth/thread-edge floor.

Run the complete proof with:

```bash
make export
make slicecheck
make wallcheck
make jointcheck
```

`make slicecheck` deliberately gives every plate a fresh worker. Repeated Bambu Studio CLI
launches in one process retain native state on macOS and previously killed the audit after a
few plates without producing a verdict.

## Material and plate policy

The canonical project is one multi-plate `exports/bambu.3mf`, as requested. Bambu stores one
global filament profile for this hand-generated project, so it opens with Generic PLA settings.
Select the following plates and change their filament preset before printing:

| Plates | Material | Reason |
|---|---|---|
| Chassis, Neck and pan | PLA acceptable; PETG preferred for load parts | Large structural shells and bearing retention benefit from creep resistance. |
| Head | PETG for back frames/panels, screen tray and door; PLA acceptable for bezel/cosmetics | The enclosed Pi can heat the tray and rear shell above comfortable PLA creep temperatures. |
| Antennas | PETG preferred for gears, axles and rack; PLA acceptable for bracket/masts | PETG survives repeated tooth contact and journal motion better. Grease journals lightly. |
| Worm drive | PETG | Repeated sliding contact and motor heat. Print at fine layers. |
| Track gear and Track links | PETG | Impact, hinge fatigue, idler tension and tooth wear. |
| Track coupon | Same PETG spool intended for the final tracks | Two 5-link PIP strips (Ø2.7 production + Ø2.56 tight-gap) + master + keepers: static PIP gate, then the powered coupon (docs/ASSEMBLY.md) before any strip plate. |
| Hardware stand-ins | PETG preferred | These are temporary functional substitutes; metal remains the final hardware. |

For Generic PETG on textured PEI, start near 250 °C nozzle / 80 °C bed, dry the spool,
and retain the encoded brim/support choices. The exporter prints the material warning in its
manifest so it cannot be missed.

## Orientation audit

| Group | Encoded orientation | Support decision |
|---|---|---|
| Open chassis shells | Open side upward; seam and nut access remain exposed | Tree support only where specified; six walls on structural shells. |
| Deck plates | Cosmetic top face toward the bed | Structural tree support for underside bosses. |
| Side panels | Upright on their integral rib feet | Tree support catches boss bottoms; wheel beams remain round and accessible. |
| Head bezel | Glass face toward the bed | Tree support; aperture and pockets open upward. |
| Head-back frames | Front face toward the bed | No back-wall ceiling remains after the four-piece split. |
| Head-back panels | Outer flat wall toward the bed | Rebates, nut mouths and locating pockets face upward. |
| Screen tray | Mount plate toward the bed, pillars upward | Structural tree support. |
| Antenna gears | Gear axis vertical, face on bed | Support disabled to protect tooth and bore surfaces. |
| Antenna output shafts | Axis vertical with the lower gear providing the footprint | Support disabled; auto brim stabilizes the 82 mm print. |
| Antenna masts | Laid horizontally with rack upward | Tree support under the cylindrical mast; rack teeth stay unscarred. |
| Pan race/cage/clips | Flat as modeled | Minimal support; bearing surfaces remain horizontal. |
| Worm pair | Gear face / worm shaft end on bed | Fine contact surfaces; tree support enabled conservatively. |
| Running-gear wheels | Axis vertical; data-driven flip puts the large disc down | Support disabled so D-bores and bearing seats are not scarred. |
| PIP track strips | Grouser-down on keel feet | Support disabled. Integral hinge gaps must remain free. |
| Track keepers | Rolled onto their wide faces | Support disabled. |
| Long printed tilt axle | Horizontal and 45° diagonal across the bed | Support disabled; metal Ø5 rod is preferred in the final build. |

## Before committing to long prints

1. Print the `Track coupon` plate in the final track material (two 5-link strips:
   production Ø2.7 + tight Ø2.56, plus master + keepers).
2. Flex all five PIP joints on each strip. They must break free without tearing the
   integral pins. Run the powered coupon protocol in `docs/ASSEMBLY.md` before any
   strip plate.
3. Test the master link, both keeper bars, M2 inserts and Ø1.75 filament boundary pin.
4. Print one antenna motor gear and confirm the double-D socket on the actual 28BYJ shaft.
5. Print one compound idler/output pair and verify free rotation on the Ø3.9 axle in the
   Ø4.2 bracket journal after elephant-foot cleanup.
6. Print the tilt D-key coupon documented in `docs/ASSEMBLY.md` before the full axle stack.
7. Measure bought bearings, motors and boards before printing dependent seats. Typical/vendor
   dimensions in CAD are not a substitute for calipers.

## Known limits

- Successful slicing does not prove a tall narrow part will survive vibration. Keep the encoded
  brims, clean the plate, and slow the first layer for shafts and masts.
- Plastic bolt, nut, bearing and axle stand-ins are for dry assembly and low-load testing. PLA/PETG
  creep and wear remain fundamentally worse than metal.
- The optional arms are visual placeholders and are excluded from the printable mechanism audit.
- Auto support is intentionally disabled on PIP tracks, gears, bearing seats and journals because
  support scars would destroy the working surface. Do not globally enable support on those plates.

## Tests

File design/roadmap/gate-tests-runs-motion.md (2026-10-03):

---
slug: gate-tests-runs-motion
title: make gate-tests must run the motion driver unit tests
state: shipped
lens: spec-gap
created: 2026-10-02
updated: 2026-10-03
metric: make gate-tests runs motion driver unit tests
before: 0 (python3 scripts/measure_gate_tests_runs_motion.py, 2026-10-02, origin/main 32b5fd4)
target: 1
measure: python3 scripts/measure_gate_tests_runs_motion.py
evidence:
  - design/roadmap/evidence/2026-10-02-gate-tests-runs-motion-before.txt
slices: 1/1
after: 1
---

# make gate-tests must run the motion driver unit tests

## Why, against the channel goal

There is no GOAL.md. The channel goal is at least three accepted improvements
each week and zero repeat of the same request. GitHub Actions now runs both
`tests/` (32 CAD geometry tests) and `software/motion/test_steppers.py` (19
pure-Python stepper tests) on push/PR. The local front door does not.
`Makefile` `gate-tests` only discovers `tests/`, and `assembly-release` starts
with `$(MAKE) gate-tests`. A broken stepper driver still gets a green local
release. The CI leftover is gone (`python3 scripts/measure_ci_unit_tests.py`
prints 1 on origin/main `32b5fd4`). This leftover is the unwired local gate
that can still ship the same class of miss.

Capture: `design/roadmap/evidence/2026-10-02-gate-tests-runs-motion-before.txt`.
`python3 scripts/measure_gate_tests_runs_motion.py` on origin/main
`32b5fd4795323a585de76ff42765ebac850a5383` prints `0`.

## What better looks like

The `gate-tests` recipe runs the motion suite as well as `tests/`
(`cd software/motion && python3 -m unittest test_steppers`, or equivalent).
`python3 scripts/measure_gate_tests_runs_motion.py` prints 1. The markdown
file is not what flips the number. Comments in the recipe do not count.

## Slices

- [x] The `gate-tests` recipe body runs software/motion tests. The measure
  prints 1. Invert: delete that uncommented line (leave the CAD discover
  line), and the measure prints 0.

Out of scope: GitHub Actions, CAD geometry, printing the robot, and
rewriting `assembly-release` beyond what `gate-tests` already covers.
Those are not this proposal's number.

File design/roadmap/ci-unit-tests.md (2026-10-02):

---
slug: ci-unit-tests
title: CAD and motion unit tests must run on GitHub Actions
state: shipped
lens: spec-gap
created: 2026-09-29
updated: 2026-09-30
metric: CAD and motion unit tests run on GitHub Actions
before: 0 (python3 scripts/measure_ci_unit_tests.py, 2026-09-29, origin/main 347b0b5)
target: 1
measure: python3 scripts/measure_ci_unit_tests.py
evidence:
  - design/roadmap/evidence/2026-09-29-ci-unit-tests-before.txt
slices: 1/1
after: 1
---

# CAD and motion unit tests must run on GitHub Actions

## Why, against the channel goal

There is no GOAL.md. The channel goal is at least three accepted improvements
each week and zero repeat of the same request. `make gate-tests` already
discovers `tests/` (32 CAD geometry tests) and `software/motion/test_steppers.py`
already holds 19 pure-Python stepper tests. Both suites pass locally. The only
Actions workflow on origin/main `347b0b5` is `.github/workflows/pages.yml`,
which deploys `web/` to GitHub Pages and never invokes unittest. Landing a
`tests.yml` that wires those suites was requested more than once and never
reached origin, so the same request repeats. Pages cannot see unit-test
greenness. This leftover's number is that missing CI.

Capture: `design/roadmap/evidence/2026-09-29-ci-unit-tests-before.txt`.
`python3 scripts/measure_ci_unit_tests.py` on origin/main
`347b0b560c151f56a4e89364b46db45ca5467971` prints `0`.

## What better looks like

A GitHub Actions workflow triggered on `pull_request` or `push` runs both
suites: `python3 -m unittest discover -s tests` (or `make gate-tests`) and
`python3 -m unittest test_steppers` under `software/motion`.
`python3 scripts/measure_ci_unit_tests.py` prints 1. The markdown file is
not what flips the number.

## Slices

- [x] Land a workflow under `.github/workflows/` that runs both suites on
  pull_request or push. The measure prints 1. Invert: delete that workflow
  (leave `pages.yml`), and the measure prints 0.

Out of scope: printing or assembling the robot, CAD geometry, and the
`workflow` OAuth grant needed to push a workflow file. Those are not this
proposal's number.

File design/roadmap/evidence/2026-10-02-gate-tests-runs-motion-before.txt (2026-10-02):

origin/main 32b5fd4795323a585de76ff42765ebac850a5383
python3 scripts/measure_gate_tests_runs_motion.py
0
exit=0

The proposal file is still absent. The instrument reads Makefile on this
checkout of origin/main. The gate-tests recipe is only
`python3 -m unittest discover -s tests -p 'test_*.py'`; it never enters
software/motion, so the measure prints 0. Invert: an uncommented
`cd software/motion && python3 -m unittest test_steppers` line in that
recipe printed 1; removing it printed 0; a comment-only copy of that line
stayed 0. python3 scripts/measure_ci_unit_tests.py on the same checkout
prints 1: Actions already runs both suites. There is no GOAL.md frozen walk.

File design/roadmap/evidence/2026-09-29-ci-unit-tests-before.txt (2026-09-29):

origin/main 347b0b560c151f56a4e89364b46db45ca5467971
python3 scripts/measure_ci_unit_tests.py
0
exit=0

The proposal file is still absent. The instrument reads .github/workflows on
this checkout of origin/main. Only pages.yml exists; it deploys web/ to Pages
and never invokes unittest. tests/ (CAD geometry) and
software/motion/test_steppers.py are present but unwired in CI, so the measure
prints 0. Invert: a temporary tests.yml that runs both suites on pull_request
printed 1; removing it printed 0. There is no GOAL.md frozen walk.

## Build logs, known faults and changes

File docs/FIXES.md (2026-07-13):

# Mechanism fix ledger, mechanisms-finalize

Three review agents (geometry verifier / mechanical loads / assembly walk) audited commit
`fa13f64` and converged on ~20 verified defects. Four fix stages run sequentially (they all edit
`src/build.py`); stage 4 is an independent re-verification. Status legend:
`[x]` fixed+probed, `[~]` in progress, `[ ]` queued, `(!)` accepted-as-is with reason.

## Stage 1, chassis + pan stack  [DONE, all probes pass]

- [x] **No chassis deck** (worst defect: race/balls/platform floated; whole head load hung on the
  pan motor's 5 mm plastic shaft). Cavity now stops `deck_t=20` below the top (5 mm of material
  under the race seat); seat floor z=37 carries the ring.
- [x] **Race grooves too deep + oversize** (platform sank 3.0 mm onto the ring; ring groove floor
  was 0.1 mm). Grooves engage 1.8 mm of ball each, oversize 0.2; stack derived in one helper
  (`_pan_stack`); plate 7.6 thick, top flush at z=52; tangency probe error 0.0000.
- [x] **No uplift retention**, 3 L-clips at 120° screwed to deck pockets, engaging a platform rim
  REBATE below deck level (top-side clips would be sheared by the neck sweep, measured r≤62.9).
- [x] **Pan D-bore jammed on the round shaft section**, D-profile now only over the flat zone
  (z 44.5..52), Ø5.3 round counterbore below; hub stops 0.3 above the motor's Ø9.1 boss.
- [x] **Platform overconstrained** (located by shaft AND race): D-bore arcs opened +0.27/side,
  flats snug: race locates, shaft only drives. Hub grub deleted.
- [x] **Pan motor pad/ear mismatch** (can sank 5.5 into the pad, ears floated 12.4 above pilots),
  pedestal top at the ear plane, Ø29 can relief, Ø2.5 pilots, wiring-box relief.
- [x] **Neck bolts broke the platform rim + all pilots were Ø3.5 clearance (nothing bites)**,
  bolt circle r16→12, neck pilots Ø2.5×12, underside counterbores for the heads.
- [x] **JST won't pass Ø12 bores**, platform + neck passes are 16×8 obrounds.
- (!) Cable exit relocated to (12,−24): the spec position (0,−38) punches the fixed race ring.
- (!) Marginal, unfixed: outer neck-bolt counterbores nick the groove outer flank ~0.9 mm (outside
  ball contact); neck bottom coplanar with deck top (zero-gap rub when panning).

## Stage 2, tilt drive + neck + Pi + axle  [DONE, all probes pass]

- [x] **695 bearing seats sealed inside the cheeks**, open flush to the inner faces (x=±18),
  bore Ø12.85. Probe: Ø12.7 test plug vs neck = 0.000 mm³ both sides (insertable).
- [x] **Worm wheel freewheels / rubs / unconstrained axially**, width 7 centered on x=0,
  grub-keyed hub (M3 pilot), Ø8 spacer tubes to both 695 inner races. Probe: wheel spans
  x −18.00..+18.00 (races at ±18), wheel-vs-neck = 0.000 mm³.
- [x] **Tilt speed 16 s per 60°**, worm_wheel_teeth 24→12; center distance factored into
  `worm_cd()` (one helper, both former call sites). Probe: teeth=12, cd=11.50.
- [x] **Worm undriveable**, full-depth double-D bore (vol 845 vs 942 unbored), worm_len 16,
  Ø6 tail stub riding a Ø6.4 bushing post off the bracket. Probe: worm-vs-neck = 0.000 mm³.
- [x] **Tilt motor buried + ear holes 7.9 mm off**, Ø29 can pocket + wiring-box and ear-bar
  reliefs; motor ROLLED about its shaft so the 7.875 offset points UP (can hangs below the worm
  axis, clear of the back-wall sweep; ears horizontal at the CAN axis); gear face on the plate
  back face. Probe: motor-vs-neck = 0.000 mm³.
- [x] **Pi 5 inside the mechanism volume**, Pi now PORTRAIT (85 edge vertical) and offset to
  x −84..−28: everything on the neck stays inside |x|≤26, so no tilt angle can reach it.
  Standoffs moved to the new 49(X)×58(Z) pattern, 3 mm long, all four rooted outside the slot;
  pivot bosses shortened 24→12 so the −X one clears the board. Probe: pi vs
  neck/motor/worm/bezel/back/axle/screen = 0.000 mm³ at −30/0/+30 (and every 5° between).
- [x] **Axle end-grip topology**, Ø7 clamp-boss torque tubes from x=±27 out to the side walls,
  Ø2.5 grub pilots at x=±30 (driven from below through the slot), snug Ø5.1 bore at the bosses,
  far-wall bores demoted to loose Ø5.3. Probe: boss material 489 mm³/side; a Ø5.24 plug bites
  the boss 4.97 mm³ (grips) and the wall 0.00 (loose slip fit).
- [x] **Tilt envelope −11°..+19° vs ±30° spec**, full ±30 achieved, no ±25 fallback. Neck slot
  narrowed to 62 wide (cheeks end at |x|=26; Pi bosses keep wall roots) but raised to z=191;
  the bottom-CENTER bezel↔back post swept into the neck column, replaced by a pair at x=±40.
  Probe: sweep −30..+30 at 5°, 14 fixed-vs-head pairs, all 0.00 mm³.
- [x] **Tilt ULN2003 had no mount**, 4× Ø6 standoffs + M3 pilots on the column back face
  (35×32 pattern centered z=110). Probe: 746 mm³ standoff material behind the back face.

Stage-2 side effects for Stage 3: the Pi is portrait at (x −56, y −16, z 192.5) → re-aim the
back-cover I/O slot for ports exiting the board's ±X/±Z edges there; bezel↔back fastening is now
7 posts (M3×35 ×7, nuts +1); pivot bosses are 12 long (they still protrude past the outer wall,
the Stage 3 trim item stands).

## Stage 3, head/screen/camera + tracks  [DONE: head/camera 3a, tracks/drive 3b]

Head/camera fixed by the Stage-3a agent (attempt 2). Combined screen+Pi model swap (user design
change) done FIRST; several fixes below were re-scoped by what the new mesh + official CM3 data
proved.

- [x] **Screen+Pi combined reference model**, `screen_ref_stl` → `..._-_Pins_Out_v8.stl` (display
  WITH the Pi on its own 58×49 back standoffs; bbox 192.96 × 38.01 × 110.76, 13.02 deeper on the
  back). `load_screen()` now anchors the GLASS FACE at local y=12.494 instead of the bbox centroid
  (which the deeper back dragged 6.51 forward). Probe: glass world y old 30.9940 / new 30.9940,
  delta 0.0000; all 4 scr_mount_pts vertex clouds delta 0.00; W/H bounds delta 0. The separate
  `pi5` placeholder part and the stage-2 Pi standoffs in head_back are REMOVED (obsolete).
- [x] **Screen retention → REAR standoffs** (re-scoped from "shorten bezel bosses"): the factory
  126.2×65.65 holes open BACKWARD; the old bezel bosses ran forward from the tab plane (25.03)
  through the GLASS (front 30.99; 69/50k screen samples inside them). Now 4× Ø9 standoffs on
  head_back (inner wall −27 → tab plane 25.03, at x=±63 they clear the Pi stack |x|≤48.1, tubes,
  louvres, both slots), each with a Ø6.5 driver channel through the back wall + 8 mm M3 seat
  (stock M3×12). Probe: material beyond the tab plane 0.000 ×4, 215.6 mm³ seat each.
- [x] **Camera aperture per OFFICIAL CM3** (ledger's Ø10→Ø18 guess superseded by RP-008153-DS):
  Ø6.3 through-bore, countersink to Ø8.0 at the outer face at 45°/side, `cam_lens_dz` kept 2.47.
  Probe: 75° diagonal FoV cone (Ø2.63 pupil 3 mm behind the face) vs bezel = 0.0000 mm³.
- [x] **CM3 does not fit the old forehead, bay redesigned** (proven, not styled): the stack needs
  ~14 mm between the window top (229.9) and the interior ceiling; 243 top gave 9.1, so the board +
  connector punched the top wall 347.6 mm³, all 4 M2 bosses floated in the pocket void and punched
  the display panel band (measured y 25.03..30.99), and the barrel crossed the module's top edge.
  Fix: `body_z_top` 243 → **251** (+8 forehead), `cam_lens_z` 233.5 → 237.0, bosses moved onto a
  ceiling-hung PIER behind the panel top strip (`cam_pier_*`, 0.53 clear of the panel; AF-housing
  cutout; 1 mm bosses, blind Ø1.7 pilots). Probe: cam|bezel/back/cover = 0.0000, cover|bezel =
  0.0000, board top 246.46 vs ceiling 247.0, barrel bottom 234.12 vs module top 233.4,
  screen-samples inside cam/cover = 0, FoV cone 0.0000.
- [x] **cam_cover fastening**, 2× M2 through the cover into the diagonal boss pilots
  (`cam_m2_clear_r` now used) + ribbon pinch slot; cover trimmed to board height (a +2 skirt
  punched the new ceiling). Probe: pilot voids 0.00 (fully drilled), self-tap annulus present,
  cover watertight.
- [x] **Glass-lip interference** (found by sampling, not in the original ledger): glass front
  30.99 sits FLUSH with the face (31), so the 0.5-deep retaining lip interpenetrated it 0.49 mm,
  the module could not seat on its factory-screw mounts. The pocket now pierces the face (front
  31.1): flush edge-to-edge glass, pocket side walls locate, factory screws retain. Probe: the
  lip-band screen-in-bezel sample cells are gone.
- [x] **Pi I/O slot re-aimed at the REAL Pi** (combined mesh, landscape on the display standoffs,
  stack x −37.7..48.1, y −7.0..+5.5, z 151..207.5): ETH+USB short edge faces +X → slot through the
  RIGHT side wall at y −8.5..6.5, z 191.5..208.5 (the band 165..191 belongs to the pivot boss).
  USB-C + 2× HDMI exit the BOTTOM long edge into the open interior → route out the existing
  bottom-rear neck slot/cable port. Old left-wall + top-wall slots removed (nothing exits there;
  GPIO pins point −Y). Probe: residual wall in slot path bezel/back = 0.0000.
- [x] **Bezel side posts pulled in 5 mm** (stage-2 agent had done it; verified) + layout reworked:
  the top-CENTER post's M3 shank ran through the CM3 board (x=0, z=238.4) and the raised ceiling
  left it unrooted → top posts are now a PAIR at x=±40 fused to the new ceiling; side posts at
  0.75·hh (z≈223), above the new I/O slot. **8 posts total (M3×35 ×8, nuts ×8).** Probe: bezel
  x-bounds exactly ±102.50.
- [x] **Pivot bosses trimmed flush** (stage-2 shortening already left nothing proud; verified).
  Probe: bezel/back material outside |x|=102.5 = 0.0000 both sides; bounds ±102.50.
- [x] Regression: head parts tilt sweep −30/0/+30 vs neck = 0.0000 all angles; bezel/back/cover
  watertight; EXPORT=1 rewrites all STLs (bezel 93818 mm³, back 178880 mm³, cover 1317 mm³).

**[x] RESOLVED (Stage 2R): combined screen+Pi stack vs the TILT MECHANISM.** User call: keep the
Pi on the display back, rework the tilt geometry. The **tilt axle moved BACK 18 mm** to
**(y −18, z 178)** (`tilt_axis_y` new param; `tilt_axis_z` unchanged; screen anchored separately via
`screen_cz`, it did not move). Everything keyed off the axle moved with it: cheeks, 695 seats, clamp
tubes/hubs/grubs, wheel, axle, worm group. Consequential rework, all probe-driven:
cheek boxes now stop AT the axle + a Ø19 bearing hoop (kills the pre-existing 260-sample cheek-top
overshoot into the display back; worst cheektop→display gap now **3.12 mm @ −30°**); worm group sits
4 mm further behind the axle (face offset 4→8) with the bracket plate shortened 46→36 tall (old top
clipped the head back wall at +10..+25°); the outboard bushing post, which both crossed the −30°
swept stack and clipped the wheel-tooth circle, became an **open-top cradle** (arm+riser+pad hugging
the measured swept-stack profile; worm separation force presses the Ø5 tail stub down into the
groove, so open-top is load-correct); gusset front pulled to y −20; column front-top notch
(y −21..−13, z 94..112) clears the head bottom-wall arc at −30°. Probes (12k stack surface samples +
manifold booleans): stack vs {neck, worm, motor, axle, wheel, head shell} intersection **0.000 mm³ at
every tilt −30..+30 step 5**; min gaps stack→neck **1.62 mm @ −30°**, stack→worm 2.71, stack→motor
16.8, stack→axle 8.5, stack→wheel 11.0 (all ≥ the 1.0 mm target); real bezel+back sweep vs
neck+worm+motor 0.000 at all 13 angles; worm cd = 11.500 exact; wheel|cheeks 0.000; Ø12.85 seat
plugs 0.000 both sides; neck_clevis/head_back/head_bezel watertight, EXPORT=1 clean.
Tracks/drive fixed by the Stage-3b agent. Measured-param corrections applied first (audit corr.
1/3/4/5 + reference/tt-motor-1079893/NOTES.md): `sprocket_outer_d` 42.0 → 37.6, `track_wheel_r`
19.0 → 19.32 (exact 12T × 10.0 polygon), pin bores Ø2.0 (new `track_pin_bore_d`), `track_pitch`
comment fixed (reference pitch is 9.65; our 10.0 is a re-model by design).

- [x] **Track loop below ground**, wheel centres raised to `_track_zc()` = R + 4.5 + 1.5 =
  25.32 so the bottom-run grouser face IS the ground line; road wheels + idler ride the knuckle
  crowns (r 15.82 about the pins) with 0.12/0.10 running clearance, since the sprocket needs the
  central ±4.9 channel open and the pad inner web (radial 21.12) is above the crowns. Probe:
  loop min z 0.0000 both pods, sprocket min z 6.52, roadwheels/idler vs links 0.0000.
- [x] **Sprocket bore → TT double-D** (`_sprocket`, not `dbore_neg`): socket Ø5.65 / 3.85 flat
  gap (print clearance on the measured Ø5.40/3.70), 8.0 deep = the flat length; tooth boxes
  truncated to the exact 18.80 tip circle; inboard hub OD12 reaches x=±58.3 through the wall
  web; Ø6 free bore + Ø9 × 1.7 counterbore on the outer face for the M2 retaining screw +
  washer into the shaft tip's Ø2 axial hole. Probe: tip r 18.800, sprocket|links 0.0000,
  sprocket watertight.
- [x] **TT motor rebuilt measured + real wall mount**, `motor_tt()` now: gearbox 36.80 × 22.40
  × 18.64 + Ø22.4 collar (flat on the shaft side) + can Ø20/14.99 AF + Ø9.9 × 2.2 boss + shaft
  Ø5.40/3.70 flats 8.8 proud, PERPENDICULAR to the body, 11.5 behind the front face. Motor sits
  INSIDE the chassis (gearbox face 0.1 off the wall inner face), shaft axis = sprocket axis.
  Chassis mount per NOTES.md: Ø8 wall pass (clears the Ø7.2 boss), outer Ø17 recess → 3 mm web,
  2× Ø3.2 M3 through gearbox + wall at 17.5 c-c (nuts in the pod gap), Ø4.2 × 2.2 nub pocket
  (y −49), tab pocket + Ø2.8 hole in the rear wall (y −74), deck pocket to z 36.8 (seat floor
  37, race ring r34..46 clear at r≥50.2), cavity-corner relief; ULN standoffs shifted +20 Y and
  vent i=−3 dropped (both collided with the motor envelope). Probe: motor|chassis 0.0000,
  motor|pod 0.0000, shaft-vs-sprocket axis delta 0.0000 both sides.
- [x] **Links re-modeled articulated** (`_track_link`): pad web + grouser + interleaved knuckle
  combs (near A ±9.4..14 / far B ±4.9..8.9, X-disjoint at the shared pin so articulation can
  never bind), Ø2.0 pin bores for Ø1.75 filament, 45° inner-face draft chamfers at the web
  ends. Probe: all 36 adjacent pairs 0.0000 mm³ both pods (worst 0.0000), link watertight,
  track_L/R export as 52 watertight bodies each.
- [x] **Idler tension slot + F688ZZ seat**, idler wheel r 15.7 × 18 wide with Ø15.95 press
  seat through, Ø18.5 × 1.0 flange recess on the inboard face; chassis grows a wall arm +
  Ø28 slotted plate inside the front loop arc (everything radial < 15.7 so the wrapping links
  clear), obround Ø8.2 slot with ±`idler_slot`/2 = ±2 Y-travel for the Ø8 stub axle (hardware;
  M3 set-screw lock). Probe: seat r 7.9750 / recess r 9.250 exact, idler|links 0.0000,
  chassis|pod 0.0000.

Notes for stage 4 / buy list:
- The tt-motor reference CAD is SINGLE-shaft; purchased TT motors are often dual-shaft. If the
  real unit has a rear shaft, the far pod side needs a Ø7.5+ clearance pocket mirrored about the
  gearbox (currently nothing is there, the pods have no outboard wall, so it only matters if
  a pod wall/cover is added). Verify the actual motor before closing that side.
- `body_z_top` grew to 251 in stage 3a (head +8, CoM higher): size the chassis ballast for the
  taller head when the buy list is done, keep the mass in the chassis floor, wheelbase is 120.

## Stage 4, independent re-verification  [DONE: NOT READY, 2 blocking + 2 minor defects]

Independent probes (own scripts, `scratchpad/stage4_*.py`), nothing reused from stages 1-3b.
Method note that invalidates several earlier "0.000" claims: the screen reference mesh is NOT
watertight, and `trimesh.boolean` with engine=manifold RAISES on it. The earlier probes' `ivol()`
caught that exception and returned 0.0, so every prior "stack vs X = 0.000 mm3" boolean was
vacuous (their ProximityQuery gap numbers were real). Stage 4 re-tested all screen pairs by
surface-sample containment (30k-400k samples) against the watertight partner.

### Category results

| # | Category | Verdict | Numbers |
|---|---|---|---|
| 1 | Build health | PASS* | plain + EXPORT=1 exit 0, 20 parts; 10 STLs written; every body watertight. *neck_clevis exports as 5 DISJOINT bodies (defect D4) |
| 2 | Collision matrix (190 pairs, neutral) | FAIL | defects D1, D2, D3. Intended contacts confirmed: pan_balls tangency 0.030 mm3 total (18 balls, mesh discretization), worm/wheel placeholder gear mesh 19.8 mm3 |
| 3 | Kinematic sweeps | PASS | tilt -30..+30 step 5: all solids 0.000, screen samples in others 0, all 13 angles. pan -90..+90 step 15: 0.000 except pan_platform vs the STATIC motor_pan shaft mesh (2.4..15.2 mm3 growing with angle; the shaft co-rotates in reality, model artifact) + the constant 0.03 ball tangency |
| 4 | Pan stack | PASS | ball tangent both grooves 0.0000; platform top z 52.0000 flush with deck 52.0000; race ring 37.0000..42.0000; clips 0.000 at rest and at +0.3 lift, 10.13 mm3 bite at +0.5 (0.4 shoulder clearance then retention), clip tops z 52.000; D-profile only in the flat zone; platform-motor_pan 0.0000 at pan=0. Note N1 |
| 5 | Tilt drive | PASS* | worm_cd() 11.500 vs mesh axis distance 11.500, delta 0.0000; lead angle 9.46 deg (<10, self-locks); Ø12.85 seat plugs 0.0000 both cheeks; wheel+spacers span exactly x -18.00..+18.00; wheel-neck 0.0000; grub pilots at x=+-30 open (rod 0.0000); Ø5.20 axle plug bites the clamp bosses 9.44 mm3/side, outer walls loose 0.0000. *but the drive carries D2 + D3 |
| 6 | Screen + camera | FAIL | mounts at (61.61/-64.59, y 25.03, z 146.15/211.80); Ø3.2 screw paths + Ø6.0 driver channels through head_back all 0.0000; glass 30.994 vs face 31.0 (flush); 75-deg FoV cone (Ø2.63 pupil 3 mm behind the face) vs bezel 0.0000; cam vs bezel/back/cover and cover vs bezel/back all 0.0000; M2 cover paths drilled, 5.22 mm3 self-tap bite into bezel pilots, pilots ~3.8 deep. FAIL because of D1: the screen cannot SEAT |
| 7 | Tracks | PASS | loop min z +0.0000 both pods; sprocket tip r 18.800 exact; sprocket-link, idler-link, roadwheel-link, and all 36 adjacent link pairs 0.0000 per pod; motor shaft vs sprocket axis delta (0.0000, 0.0000) both sides; motor-chassis, motor-pod, sprocket-chassis, pod-chassis 0.0000; idler bore r 7.9750 (F688ZZ Ø15.95), Ø18.5 flange-recess ring present both pods |
| 8 | Cable route | PASS* | deck pass at (12,-24) clear z 30.25..55 (platform 0.000, race 0.000); platform slot mouth at (0,-38) clear; Ø7 rod up the neck channel z 52..150 = 0.000; head bottom-rear slot clears a drape capsule vs bezel/back 0.000 at tilt -30/0/+30. Notes N2, N3 |
| 9 | Docs drift | FAIL | 9 stale claims in CLAUDE.md, listed below |
| 10 | Renders | PASS | chk_iso/side/front/top/sec_* shot via port 8770, downscaled and inspected: assembly coherent, tracks on the ground line, screen framed, camera lens visible on the forehead, no floaters / z-fighting / missing parts |

### DEFECTS

- **D1 [FIXED, stage 5] (BLOCKER, stage 3a) - screen rear standoffs punch the display's own mount bosses.** The
  Pins-Out reference mesh has a raised boss/tab structure around EACH factory hole spanning
  y 22.53..25.03 (2.5 mm), annulus r 1.5..8.1 about the hole axis. The Ø9 head_back standoffs run
  solid to y=25.03 (the hole plane, which is the FRONT of that boss, not its base), so at all 4
  mounts an annular band r 1.75..4.49 x 2.5 mm deep interpenetrates (386/6.2k local surface
  samples inside head_back, max depth 1.37 mm, identical at all four sites). The screen cannot
  seat; it would stand 2.5 mm proud. Fix direction: stop the standoffs at y=22.53 or counterbore
  them to swallow the display boss. Stage 3a's "material beyond the tab plane 0.000" probe only
  checked y>25.03 and missed this.
- **D2 [FIXED, stage 5] (BLOCKER, stage 2R) - tilt worm interpenetrates the open-top cradle: 97.9 mm3**, bounds
  x -5..+5, y -24.5..-14.5, z 161.25..166.5. The cradle arm/riser/pad band (y -23..-11, groove
  r 2.7) was sized for the Ø5 tail stub, but the worm carries full-radius threads (r 5.34) all
  the way to y=-13.5; the bare stub emerges only for the last 0.5 mm (worm ends y=-13.0). About
  9.5 of the 12 mm cradle band sits under the thread envelope; the worm cannot rotate. Root
  cause: the stub (y -21..-13) is modeled INSIDE the threaded length; stub and cradle must both
  move past the thread end (or the worm shortens).
- **D3 [FIXED, stage 5] (minor, stage 2) - worm double-D bore clocked 90 deg to the motor shaft flats: 17.4 mm3**,
  bounds x -1.5..+1.5, y -30.5..-26.25 (the shaft's round shoulders buried in worm core). After
  the motor's two rotations its flats face +-X, but `db.apply_transform(R(TAU/4,(0,1,0)))` leaves
  the bore flats facing +-Z (the in-code comment claims +-Z is correct; it is not). One-line
  clocking fix; the placeholder encodes assembly intent so it should be right.
- **D4 [FIXED, stage 5] (minor, stage 2) - neck_clevis is 5 disjoint bodies.** The 4 tilt-ULN standoffs (Ø6x8 at
  x +-17.5, z 94/126) span y -69..-61 and are only FACE-TANGENT to the column back face (y=-61);
  `uni()` does not fuse tangent solids. 186.6 mm3 each, floating in the STL. Push them 1-2 mm
  into the column.

### Notes (no geometry change required)

- N1: pan D-flat engagement is 3.5 mm effective, not 7.5: the Ø5.3 round counterbore is cut
  `d_bot - hub_bot + 4` long and overshoots 2 mm into the flat zone (to z 46.5; shaft flats span
  z 44..50). Works, but half of what stage 1 claimed; trim the +4 if more bite is wanted.
- N2: the cable corridor from the neck-channel mouth (z=150) into the head necks down to a ~Ø5
  free disc (max inscribed radius 2.5 mm at z=160), squeezing between the tilt-motor can (blocks
  x<~14 up to z~173) and the +X cheek (blocks x>18). The documented Ø3.6 power pair passes with
  a jog; nothing thicker does. A straight Ø7 bundle does NOT fit (768 mm3 vs the motor can).
- N3: chassis cavity furniture at (x 8.5..14.7, y -24..-20.5, z<=30.25) sits 1.7 mm below the
  deck cable-pass mouth (straight Ø7 rod clips it 18.8 mm3); a flexible bundle routes around.

### Docs drift (CLAUDE.md; found, not fixed)

1. "9 watertight per-part STLs" (l.11) and the "9 printed parts" list (l.178): now 10;
   `pan_clips` missing from both lists.
2. Worm wheel "24T" at l.68, l.121, l.144: build uses `worm_wheel_teeth = 12`.
3. Key numbers (l.114-117): screen "measured ... 193.0 x 25.0 x 110.8" + "Loaded live from
   ..._v12.stl": the build loads `..._-_Pins_Out_v8.stl` (combined display+Pi, 192.96 x 38.01 x
   110.76). `PARAMS["screen_d"]=25.0` no longer matches the loaded mesh either.
4. "Overall assembly bbox = 221 x 208 x 248" (l.117): measured 209 x 170.5 x 251 at neutral.
5. "bezel<->back: 6 perimeter posts" (l.183): now 8 posts (stage 3a).
6. "screen: 4x M3 bosses on the bezel" (l.184): retention moved to 4 rear standoffs on
   head_back with back-wall driver channels (stage 3a).
7. "Pi 5: 4x M2.5 standoffs on the back cover (58x49)" (l.186): removed; the Pi rides the
   display's own standoffs inside the combined reference mesh.
8. The stage-2R tilt-axle relocation to y=-18 (`tilt_axis_y`, `screen_cz` decoupling) is absent
   from Mechanical intent / Key numbers (only z=178 is stated).
9. Stage-1 claim above, "D-profile now only over the flat zone (z 44.5..52)": effective D zone
   is 46.5..52 (see N1).

### Verdict

**NOT READY TO COMMIT.** Blockers: D1 (screen seating), D2 (worm/cradle). D3 + D4 are small but
should ride along; docs drift items 1-8 belong in the same pass.

## Accepted findings (no geometry change)

- Worm lead angle 9.46°: self-locks dry, backdrives greased, but the 28BYJ's internal 64:1 train
  never backdrives, so the de-energized hold stands regardless. (Honest-worm option: worm_od 14.)
- Hollow-axle cable routing at Ø2.5 is fiction for a 5 A pair, the real route is the bottom-rear
  slot beside the clevis (tilt is only ±30°); the bore stays as weight relief. Docs updated.
- 18 uncaged BBs: grease-stick at assembly; a printed cage ring is a nice-to-have part.
- Axle: buy Ø5 brass/steel tube (K&S 300 mm stock); a printed axle is unusable (5.9 mm sag).

## Fastener BOM (from the assembly review; re-check after stage 3)

M3×35 ×8 (bezel↔back, stage-3a layout) · M3 nut ×11 · M3×12 ×4 (screen, from behind through the
Ø6.5 back-wall channels into the display's threaded pan holes) · M3×16 ×3 (platform→neck) · M3×8 ×2 (pan
ears) · M3 grub ×4-5 · M4×10+nut ×2 (tilt ears) · M2.5×8+nut ×4 (Pi) · M2×8 self-tap ×2+2 (camera
+ cover) · 695-2RS ×2 (owned) · F688ZZ flanged bearing ×2 (8×16×5, flange Ø18) + Ø8 stub axle ×2 + M2×16
self-tap ×2 (sprocket retain) · 6 mm BB ×18 · Ø1.75 filament pins ×72 ·
Ø5×209 tube ×1 · 28BYJ-48 ×2 + ULN2003 ×2 (owned) · TT gearmotor ×2 (own 1, **buy 1**).

## Stage 5, fix pass (D1-D4) + neck-on-platform  [DONE]

- [x] Neck base footprint r62.9 overhangs the spinning platform (r48; solid top r45 inside the
  clip rebate) and rides the FIXED deck with zero gap. Move the column in (neck_y -38 -> ~-14)
  so the whole footprint sits on the platform at r<=44. The tilt axle (y=-18, z=178) and the
  head DO NOT move (stage-2R world-coord parameterization). Move with it: 3x M3 bolt circle,
  platform cable slot, deck cable pass alignment; deepen the column front notch for the head
  chin arc at -30 deg. Re-probe: pan sweep vs deck/clips, tilt sweep, cable route, watertight.

### Stage 5 results (fresh probes, scratchpad st5_*.py; screen checked by surface samples,
### booleans raise on failure)

- **D1 fixed** - standoff bearing face moved from the hole plane to the display boss REAR
  plane: boss lip measured 2.500 (y 22.534..25.034, identical all 4 mounts, annulus census);
  new face y=22.480 (lip 2.5 + 0.05 seat clearance, `scr_boss_lip`/`scr_seat_clear`).
  Probes: 0/400k screen samples inside head_back (0 per site at all 4 mounts), 0/30k inside
  head_bezel; glass front 30.994 (flush, target 30.994 +-0.05); screw path 0/400 hits per
  mount; 6 mm seat solid 400/400 per mount.
- **D2 fixed** - worm_len 16 -> 14 + face_y offset 8 -> 9.5: thread span now y -32.00..-16.29
  = 15.71 mm = 4.00 axial pitches (>=4 teeth-equivalent), bare Ø5 stub forward of y=-16
  (max r fwd of -15.5 = 2.500); cradle groove band moved to y -15.5..-13 on the stub, riser/
  pad rear split into two side prongs by an r5.9 envelope-relief bore about the worm axis.
  Probes: worm vs neck static 0.000; ROTATION swept envelope (64-slice surface of revolution,
  max thread r 5.344) vs neck 0.000; worm_cd()=11.500 vs mesh axis distance 11.500, delta
  0.0000; wheel-worm placeholder contact preserved (32.9 mm3).
- **D3 fixed** - removed the extra `R(TAU/4, y)` clocking on the worm's double-D bore
  (dbore_neg(axis="y") already cuts flats +-X = shaft flats); comment corrected.
  Probe: worm vs motor_tilt 17.4 -> 0.000 mm3.
- **D4 fixed** - tilt-ULN standoffs lengthened 8 -> 8.5 and buried 0.5 into the column back
  face. Probe: neck_clevis = 1 watertight body (was 5 disjoint).
- **Neck-on-platform done** - `neck_y` -38 -> **-17.0** (derived: footprint max r =
  sqrt(14^2+(|ny|+13)^2)+10 <= 44 gives |ny| <= 17.98; measured 43.10 at z 52..55).
  Cascade: bolt circle re-clocked (90,210,330)r12 -> (270,30,150)r16 in BOTH neck pilots and
  platform holes (old layout put a hole 2 mm off the pan axis, inside the D-bore hub); cable
  channel decoupled to `neck_chan_y`=-26 (behind the notch; platform slot start + deck pass
  aim follow it); cheeks re-anchored at (+-22, -33, 155) on a new 52x14x10 cheek-root block
  (anchoring at ny=-17 grazed the resting stack and buried 11 mm into the -30 sweep); column
  front notch re-derived: the -30 sweep (shell chin to y=-16.7 @ z~102, display back band to
  y=-14 right up to z 150) forces the whole column front above z=94 back to y=-19.5.
  Probes: footprint max r 43.10 <= 44.0; pan sweep -90..+90 step 15 vs all fixed parts 0.000
  (only the known 0.031 ball tangency, intended contact, = stage-4's 0.030); tilt sweep
  -30..+30 step 5: head solids vs neck group all 0.000, screen samples in neck group 0 at all
  13 angles; cable route: Ø7 rod through the deck pass (12,-24, z 30.5..55) vs platform/race/
  chassis 0.000, Ø7 rod down the channel (0,-26, z 45..150) vs neck/platform 0.000; all 3
  bolt holes on solid platform (r 16.5/16.5/33.0, annulus 300/300 solid, bore open, clear of
  hub/rebate/groove/slot), neck pilot rings 300/300 solid.
- **Build health**: plain + EXPORT=1 exit 0; all 10 printed STLs watertight; single-body
  everywhere except the by-design multi-body track_L/track_R (52) and pan_clips (3).
  Renders (st5_iso/side via port 8770) inspected: assembly coherent, no floaters.

## Stage 6, independent re-verification of stage 5  [DONE: READY TO COMMIT]

Same methodology as stage 4 (own probes, `scratchpad/stage4_*.py` + `stage6_d123.py`; screen
mesh checked by surface-sample containment, booleans raise on failure, nothing reused from the
stage-5 agent's scripts).

| # | Category | Verdict | Numbers |
|---|---|---|---|
| 1 | Full collision matrix (190 pairs, neutral) | PASS | only intended contacts: pan_balls tangency 0.030 mm3 (both grooves), worm/wheel placeholder gear mesh 32.9 mm3. D1/D2/D3 pairs all gone |
| 2 | D1 screen seating | PASS | 0/400k dense samples inside head_back at all 4 mounts (was 386/6.2k per site), 0/60k global in back AND bezel; standoff bearing face measured y=22.480 (= 25.03 - 2.5 lip - 0.05 seat, exact); glass front 30.9940 flush; Ø3.2 screw paths 0.0000 x4 |
| 3 | D2 worm rotation | PASS | 40-slice revolved envelope (max thread r 5.344) vs neck 0.0000; static 0.0000; thread span y -32.00..-16.29; bare stub forward of y=-15.5 max r 2.500 vs groove r 2.7; envelope vs the tilting head (bezel+back+axle) 0.0000 at -30/0/+30 |
| 4 | D3 bore clocking | PASS | worm vs motor_tilt 0.0000; negative control (worm rotated 90 deg about its axis) 17.36 mm3, proving the flats exist and are correctly clocked; worm_cd 11.500 vs mesh 11.500, delta 0.0000 |
| 5 | D4 watertight / bodies | PASS | all 10 STLs, every body watertight; neck_clevis 1 body (was 5); multi-body only track_L/R (52) + pan_clips (3), by design |
| 6 | Neck footprint + pan/tilt sweeps | PASS | footprint max r 43.098 at z 52..55 (<= 44; also max r below z=60), neck vs platform/clips/chassis/race 0.0000; pan -90..+90 step 15 vs all fixed: 0.000 (constant 0.03 ball tangency + the known static motor_pan shaft artifact only); tilt -30..+30 step 5: solids 0.000, screen samples 0, all 13 angles |
| 7 | Bolt circle | PASS | holes at az 270/30/150, r-from-pan-axis 33.00/16.52/16.52, plate annulus 100/100 solid each, bores fully void, Ø2.3 rods through platform hole + neck pilot 0.000 x3 (aligned) |
| 8 | Cable route | PASS | Ø7 deck-pass rod (12,-24, z 30.5..55) vs chassis/platform/race 0.000; Ø7 channel rod (0,-26, z 45..150) vs neck/platform 0.000 |
| 9 | Renders | PASS | st6_iso/side/sec_mid via port 8770: column lands on the platform, assembly coherent, tracks on the ground line, no floaters / z-fighting |

Docs: CLAUDE.md drift from stage 4 is resolved (10 parts, 12T, Pins_Out_v8; the one remaining
"24T" is a historical "was 24T" note, not a stale claim).

**Verdict: READY TO COMMIT.** No defects found. Standing model-only artifacts (not defects):
static motor_pan shaft vs the swept platform D-bore (shaft co-rotates in reality), placeholder
worm/wheel tooth interpenetration (regen in BOSL2 before printing), 0.03 mm3 ball-seat tangency.

## Wallcheck gate findings (2026-07-13, skills fix campaign)

The new `make wallcheck` min-wall gate (src/wallcheck.py, in `make all`) surfaced and
closed these on its first full runs:

| Finding | Verdict | Fix |
|---|---|---|
| track_keeper_L/R tab rim 0.65 mm (Ø4.2 M2 counterbore on the 2.6x5.5 tab) | DEFECT, fixed | cb Ø4.2 -> Ø4.0 (M2 pan head Ø3.8 max) + tab 5.5 -> 5.7; rim now 0.85, slot-critical 1.9 bar untouched, keeper-wall clearance 1.35 |
| head_back_frame_L/R exported STLs non-manifold (float32 write collapses near-equal float64 vertices at the cap-plane junctions; in-memory mesh passed is_watertight) | DEFECT, fixed | geo.export_stl(): float32-quantized watertight check on every export; guarded manifold3d repair (volume < 0.1%, bbox < 0.01 mm, asserts) |
| neck_clevis 0.12 mm feather wedges (cradle-pad underside vs Ø5.4 tail-stub groove bottoming 0.2 below it) | DEFECT, fixed structurally | cooler-clearance pass deleted the pad+groove; the new crest-riding half-groove bottoms 4 mm above the block bottom; p1 now 1.75 |
| tilt_worm / worm_wheel / pan_gears sub-0.8 populations | EXPECTED geometry, whitelisted | probe-located to tooth tips, thread run-out feathers, and helical face-edge feathers; mesh probe-verified per docs/WORM.md; documented floors 0.2 / 0.4 / 0.75 |

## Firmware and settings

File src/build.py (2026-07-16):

"""desk-pi -- tracked pan/tilt robot around the real 7" touchscreen.

Coordinate system: Z up, robot looks toward +Y (screen glass faces +Y).
Origin (0,0,0) = center of the desk contact plane.

Kinematic chain (bottom -> top):
    tank chassis          fixed base with two track pods and TT gearmotor placeholders
      -> PAN joint        yaw about vertical Z, 28BYJ through a 2:1 spur GEAR-UP
                          (fast-pan 2026-07-12; ~180 deg/s peak slew)
        -> pan_platform + neck_clevis  (rotate as one on the captured-BB race)
          -> TILT joint   pitch about horizontal X, 3-start worm 4:1 (fast-tilt
                          2026-07-12; 22.5 deg/s -- NO LONGER self-locking, see PARAMS)
            -> rounded tablet head + screen/Pi + camera

The screen and Pi ride as one module inside the head. DSI/CSI ribbons stay inside the head;
only round power wires cross the pan/tilt joints. The default GLB render uses a preview pose
(`preview_pan_deg`, `preview_tilt_deg`) so motion is visible; set PAN=0 TILT=0 for neutral review.

Run:  python3 src/build.py            -> web/assembly.glb
      EXPORT=1 python3 src/build.py   -> also writes per-part STLs into stl/<subsystem>/
"""
import os
import numpy as np
import trimesh
from trimesh.transformations import rotation_matrix as R

from stlpaths import webpath, stlp
from params import DEG, EXPORT, P, TAU, tilt_worm_grub_datums
from geo import _T, _color, box, cyl, dbore_neg, export_stl, inter, sub, uni
from gears import (gear_disc, load_gear_stl, pan_gear_mesh_deg, pan_real_ok, worm,
                   worm_cd, worm_mesh_clock_deg, worm_real_names, worm_real_ok)
from screen import load_screen, screen_pose
from tracks import _spr_cz, build_tracks
from motors import antenna_motor, motor_28byj, motor_tt
import refparts
from pan import build_pan_platform, build_pan_race, build_pan_retainer
from neck import build_neck_clevis, build_tilt_carrier, build_trim_neckfoot
from head import (build_ant_drive, build_antennas, build_ant_orings, build_arms, build_cam_pod, build_hatch_frame,
                  build_ear_jacks, build_head_parts, build_head_rails, build_led_strip,
                  build_pi5_cooler, build_screen_tray, build_sd_plug)
from chassis import (build_belly_plate, build_chassis_electronics, build_chassis_parts,
                     build_chassis_base, build_fascia, build_pan_pedestal)
from fitmap import _fit_report


# ---------------------------------------------------------------------------
# Assembly
# ---------------------------------------------------------------------------
def build():
    scene = trimesh.Scene()
    zt = P["tilt_axis_z"]
    yt = P["tilt_axis_y"]

    # pose + output overrides (for generating review render sets)
    pan_deg = float(os.environ.get("PAN", P["preview_pan_deg"]))
    tilt_deg = float(os.environ.get("TILT", P["preview_tilt_deg"]))
    head_name = "head_wedge" if os.environ.get("SOLIDHEAD") == "1" else "head_shell"
    out_name = os.environ.get("OUT", "assembly.glb")

    # transforms
    pan = R(pan_deg * DEG, (0, 0, 1), (0, 0, 0))
    tilt = R(tilt_deg * DEG, (1, 0, 0), (0, yt, zt))
    M_head = pan @ tilt          # head parts: tilt then pan
    M_pan = pan                  # pan-group parts

    fit_geo = {}                     # name -> posed world mesh, for the FITS=1 pressure map
    pose_groups = {"head": [], "pan": []}   # node -> kinematic group, for the viewer's
                                            # live pan/tilt sliders (web/pose.json)

    def add(mesh, M, export_name=None):
        if mesh.metadata.get("scene") is False:      # export-only ghost (granular
            if EXPORT and export_name:               # children carry the scene; the
                g = mesh.copy(); g.apply_transform(M)  # ghost is the multi-body STL)
                export_stl(g, stlp(export_name))
            return
        g = mesh.copy()
        g.apply_transform(M)
        name = mesh.metadata["name"]
        # Bought parts: swap the analytic placeholder for the downloaded real mesh
        # (docs/ELECTRONICS.md), fitted onto the placeholder's world pose. The real
        # mesh only feeds the scene/viewer -- the placeholder still drives EXPORT
        # (never printed anyway) and the gates skip refparts like the screen mesh.
        if refparts.enabled() and name in refparts.NODE_KIND:
            real = refparts.fit_real(refparts.NODE_KIND[name], g, name)
            if real is not None:
                g = real
        scene.add_geometry(g, node_name=name)
        fit_geo[name] = g
        if M is M_head:
            pose_groups["head"].append(name)
        elif M is M_pan:
            pose_groups["pan"].append(name)
        if EXPORT and export_name:
            export_stl(mesh, stlp(export_name))

    # --- FIXED: printable split tank chassis body + two track pods ---
    for ch in build_chassis_parts():
        add(ch, np.eye(4), f"{ch.metadata['name']}.stl")
    add(build_belly_plate(), np.eye(4), "belly_plate.stl")   # bolt-on floor access plate
    add(build_pan_pedestal(), np.eye(4), "chassis_pedestal.stl")   # pan-motor pedestal
    # (round 5: bolts to the belly plate -- drop the plate, drop the pan stage)
    for fp in build_fascia():                        # front fascia set (design ref)
        add(fp, np.eye(4))
    for ep in build_chassis_electronics():           # Arduino I/O plane seat
        add(ep, np.eye(4))                           # placeholders (2026-07-13)
    for trk in build_tracks():
        add(trk, np.eye(4), trk.metadata["export"])
    # (pod_rail_L/R deleted 2026-07-14 round 3: the chassis_side panels grow the
    # wheel beam directly -- see build_chassis_parts.)

    # track drive: 2x TT gearmotor (own 1, BUY 1 more) INSIDE the chassis, gearbox face 0.1 off
    # the side-wall inner face; the shaft crosses the wall (Ø8 pass, wall thinned to a 3 mm web)
    # and the sprocket's inboard hub grips the flats just outside. Shaft axis = sprocket axis
    # (y=spr_y, z=_spr_cz(), 14T v2). Tab registers in a rib pocket; nub in a wall pocket;
    # 2x M3 through gearbox + wall, nuts in the pod gap. Skid steer.
    ax = P["chassis_w"] / 2 - 5.0 - P["tt_gearbox"][2] / 2 - 0.1
    for sx in (-1, 1):
        dm = motor_tt("drive_L" if sx < 0 else "drive_R")
        if sx < 0:
            dm.apply_transform(R(TAU / 2, (0, 1, 0)))   # mirror about Y: shaft -X, tab stays rear
        dm.apply_translation((sx * ax, P["spr_y"], _spr_cz()))     # mid-drive: shaft on
        # the ground-run sprocket axis (pin line + pin circle = 25.32), see PARAMS spr_y
        add(dm, np.eye(4))
        dm2 = motor_tt("drive2_L" if sx < 0 else "drive2_R")   # OPTIONAL 2nd TT
        dm2.apply_transform(R(TAU / 2, (1, 0, 0)))   # (2026-07-11): flipped about its
        if sx < 0:                                   # shaft so the gearbox trails -y;
            dm2.apply_transform(R(TAU / 2, (0, 1, 0)))   # then side-mirrored like dm
        dm2.apply_translation((sx * ax, P["spr_y2"], _spr_cz()))
        add(dm2, np.eye(4))                          # all fittings modeled -- populate
        # this station when the 2nd motor pair is bought (BOM: optional)

    # --- PAN GROUP ---
    add(build_pan_platform(), M_pan, "pan_platform.stl")

    neck = build_neck_clevis()                       # already built in world Z (sits on base top)
    scene_neck = neck.copy(); scene_neck.apply_transform(M_pan)
    scene.add_geometry(scene_neck, node_name="neck_clevis")
    pose_groups["pan"].append("neck_clevis")         # bypasses add(): tag its group by hand
    if EXPORT:
        export_stl(neck, stlp("neck_clevis.stl"))
    # orange pedestal collar at the column foot (neck styling pass 2026-07-12): rides the
    # platform (pan group), slipped over the column before the neck bolts down, pinned+glued
    add(build_trim_neckfoot(), M_pan, "trim_neckfoot.stl")

    # --- TILT WORM DRIVE (3-start, 4:1 -- NOT self-locking, see PARAMS worm_starts) ---
    wx = P["worm_wheel_x"]
    cd = worm_cd()
    wz = zt - cd
    wheel_r = P["worm_module"] * P["worm_wheel_teeth"] / 2
    # worm wheel keyed to the axle -> turns WITH the head (M_head). Width 7 centered on x=0,
    # round-bore hub with a radial M3 grub preloaded onto a center-only axle flat. The flat,
    # not thread friction, carries drive torque while both 695 journals stay fully round.
    # The pilot faces the open rear bay for access before the head is hung. Spacer
    # TUBES out to both 695 inner races: they react the ~10 N worm thrust / 3.7 N wheel
    # axial load (they also locate the wheel axially, so no extra retainer is needed).
    # REAL generated teeth (docs/WORM.md): 12T involute helical wheel + 3-START worm
    # (fast-tilt 2026-07-12, ratio 4:1, lead angle 23.08 -- see PARAMS worm_starts incl.
    # the SELF-LOCKING LOSS tradeoff), verified meshing at CD 11.9: 0.000 mm3 static AND
    # over a coupled full-worm-rev sweep (tools/gears/probe_worm_sweep.py).
    # PLACEHOLDER_GEARS=1 restores the readable gear_disc/worm placeholders;
    # worm_real_ok() compares the starts-keyed generator meta sidecar to PARAMS,
    # so ANY params change without a regen also falls back -- same honesty
    # convention as the antenna gears (which replaced the old hard-coded starts != 1).
    placeholder_gears = (os.environ.get("PLACEHOLDER_GEARS") == "1"
                         or not worm_real_ok())
    if placeholder_gears:
        wheel = gear_disc(wheel_r, P["worm_wheel_teeth"], P["worm_wheel_w"],
                          2.5 * P["worm_module"], axis="x")
    else:
        # toothed blank only: axis X, bore Ø5.2, width 7, centered at origin -- exactly where
        # gear_disc built; the hub/tube union, bore re-cut and grub pilot below apply unchanged.
        wheel_name, worm_name, _meta_name = worm_real_names()
        wheel = load_gear_stl(wheel_name)
        # cosmetic mesh clocking: at the assembly's relative pose (wheel midplane crosses the
        # worm at worm-local y +6), tools/gears/probe_worm_sweep.py measured starts-keyed
        # zero-interference window centers of 17.88 deg (3-start) and 25.50 deg (1-start).
        # M_head then adds tilt_deg about the SAME axis, so pre-rotate by (clock - tilt)
        # mod one tooth pitch (30) and the teeth visually mesh at ANY preview/sweep pose.
        # Physically meaningless (the wheel is 30-deg tooth-periodic). The wheel pilot
        # is cut after this transform, so its -Y clock stays deterministic.
        wheel.apply_transform(R(((worm_mesh_clock_deg() - tilt_deg) % 30.0) * DEG,
                                (1, 0, 0)))
    hub_len = P["wheel_hub_x1"] - P["wheel_hub_x0"]
    hub = cyl(5.5, hub_len, axis="x")
    hub.apply_translation(((P["wheel_hub_x0"] + P["wheel_hub_x1"]) / 2, 0, 0))
    tub_p = cyl(4.0, 9.0, axis="x"); tub_p.apply_translation((13.5, 0, 0))      # hub -> +X race
    tub_m = cyl(4.0, 14.5, axis="x"); tub_m.apply_translation((-10.75, 0, 0))   # wheel -> -X race
    wheel = uni([wheel, hub, tub_p, tub_m])
    wheel = sub(wheel, cyl(P["axle_d"] / 2 + 0.1, 40, axis="x"))                # Ø5.2 over the axle
    # Radial O2.5 pilot enters from -Y and reaches the round O5.2 bore. M3x4 seats
    # flush at hub r5.5 and its cup tip lands on the axle flat at r1.5. It is exempt
    # from the structural thread-form ban: this is the retention-grub class used by
    # the head clamps. Threads hold preload; the tip-on-flat contact carries torque.
    pilot_inner_y = P["axle_d"] / 2 + 0.05
    pilot_outer_y = 5.5 + 0.5
    pilot = cyl(P["wheel_grub_pilot_d"] / 2,
                pilot_outer_y - pilot_inner_y, axis="y")
    pilot.apply_translation((P["wheel_grub_x"],
                             -(pilot_inner_y + pilot_outer_y) / 2, 0))
    wheel = sub(wheel, pilot)
    _color(wheel, "fork"); wheel.metadata["name"] = "worm_wheel"
    wheel.apply_translation((wx, yt, zt))
    add(wheel, M_head, "worm_wheel.stl")
    # worm on the motor shaft (axis Y), tangent below the wheel; fixed to the neck frame (M_pan).
    # FULL-DEPTH double-D bore (the old worm had no bore at all). NO tail stub since the
    # Pi 5 cooler pass 2026-07-13: the tail rides a CREST-RIDING half-groove under the
    # threads in the neck (build_neck_clevis) -- the old bare Ø5 stub reached y=-12 and
    # penetrated the cooler keep-out +2.7 at the -33.8 nose-down stall.
    face_y = yt - 0.5 * P["worm_len"] - 10.0         # keep in sync with build_neck_clevis()
                                                     # (10.0 was 9.5: worm_len 14 -> 13 with
                                                     # plate/motor/carrier HELD at y -34.5)
    yc = face_y + 4.0 + P["worm_len"] / 2            # worm center y = tilt_axis_y - 6: real
                                                     # threads span exactly +-worm_len/2 ->
                                                     # world -30.5..-17.5 (see PARAMS worm_len)
    if placeholder_gears:
        wm = worm(P["worm_od"] / 2, P["worm_len"], starts=P["worm_starts"], axis="y")
    else:
        # real starts-keyed RH worm (docs/WORM.md): axis Y, OD 10.55, solid core Ø7, thread
        # span exactly +-6.5 about origin, 0.6 crest chamfer at both ends (cooler pass).
        # The Ø7 core takes the full-depth double-D bore in SOLID stock (probed: bore
        # surface 100% inside the solid over the thread span; round wall 0.915 mm, flat
        # wall 1.88 -- thin but the D-flats carry the torque).
        wm = load_gear_stl(worm_name)
    db = dbore_neg(P["worm_len"] + 1.2, axis="y")
    # NO extra clocking: after the motor's two rotations below (shaft +Z -> +Y, then rolled so
    # the offset points up) the shaft flats face +-X, and dbore_neg(axis="y") already cuts its
    # flats +-X. The old R(TAU/4, y) here clocked the bore flats to +-Z -- 90 deg off the
    # shaft (stage-4 defect D3: 17.4 mm3 of shaft shoulder buried in the worm core).
    db.apply_translation((0, 0.5, 0))
    wm = sub(wm, db)
    # FORWARD (+Y) axial retention: an M3x3 cup-point grub enters radially from +X
    # through this O2.5 pilot and bears on the shaft flat. The pilot Y is the midpoint
    # of the shaft-flat band that actually overlaps the worm, derived in params rather
    # than copied from the current pose. Cut after the D-bore for both real and placeholder
    # worms. This is a low-load retention grub, like the head axle-clamp grubs that survived
    # the fastening campaign, not a structural joint, so the O2.5 thread-form pilot ban does
    # not apply. The roughly 10 N worm thrust is reacted by the flat and grub preload.
    # M3x3 seats with its top at r 4.5, below the r 5.275 crest envelope, so it adds no
    # radial envelope. The worm prints on end; this small horizontal round bore bridges fine
    # under the CLAUDE.md teardrop rule, so no teardrop is needed.
    grub_y, _shaft_flat_band, _worm_band, _wheel_face_band = tilt_worm_grub_datums()
    pilot_inner_x = P["motor_shaft_flat"] / 2 - 0.3
    pilot_outer_x = P["worm_crest_r"] + 1.0
    pilot = cyl(P["worm_grub_pilot_d"] / 2,
                pilot_outer_x - pilot_inner_x, axis="x")
    pilot.apply_translation(((pilot_inner_x + pilot_outer_x) / 2,
                             grub_y - yc, 0))
    wm = sub(wm, pilot)
    _color(wm, "motor"); wm.metadata["name"] = "tilt_worm"
    wm.apply_translation((wx, yc, wz))
    add(wm, M_pan, "tilt_worm.stl")
    # tilt motor: shaft +Z -> +Y, then ROLLED about the shaft so the 7.875 offset points UP:
    # the can hangs BELOW the worm axis (clear of the head's back-wall sweep) and the ears run
    # horizontal at the CAN axis. Gear face lands on the bracket plate's BACK face.
    mt = motor_28byj("motor_tilt")
    mt.apply_transform(R(-TAU / 4, (1, 0, 0)))       # shaft +Z -> +Y
    mt.apply_transform(R(-TAU / 4, (0, 1, 0)))       # roll: shaft offset +X -> +Z
    mt.apply_translation((wx, face_y - 2 - P["motor_body_h"],
                          wz - P["motor_shaft_off"]))
    add(mt, M_pan)
    # removable cartridge carrier: the motor's ears bolt to it on the bench; 4x M3 from the
    # rear bay clamp it to the bracket plate (see build_tilt_carrier)
    add(build_tilt_carrier(), M_pan, "tilt_carrier.stl")

    # (Pi 5 placeholder removed: the Pi now rides the display's OWN 58x49 back standoffs and
    # is part of the combined screen reference mesh, "Pins Out" assembly. See load_screen().)

    # pan motor + FAST-PAN 2:1 spur gear-up (2026-07-12; see PARAMS pan_gear_*): the shaft
    # no longer sits ON the pan axis -- it lands CD 19.2 away at azimuth pan_shaft_azim,
    # the motor clocked -90 deg (ears along X, wiring box exits +Y, D-flats +-X) and
    # DROPPED ~13.5 so the 32T gear on its flats rides the pan_gear_z band under the seat
    # floor, driving the platform's integral 16T pinion. Peak slew 90 -> 180 deg/s.
    m_g = P["pan_gear_m"]
    cd_pan = m_g * (P["pan_gear_motor_t"] + P["pan_gear_pinion_t"]) / 2    # 19.2
    paz = P["pan_shaft_azim"] * DEG
    sx_, sy_ = cd_pan * np.cos(paz), cd_pan * np.sin(paz)                  # shaft (-19.2, 0)
    gz0, gz1 = P["pan_gear_z"]
    gf_pan = gz0 - 3.75 - 0.5        # gear face 40.75: flats (gf+3.75..gf+9.75) cover 45..50
    zsh = gf_pan - P["motor_body_h"]                 # can bottom 21.95 (2026-07-16: the
    #                                                  phantom gearbox tier is gone; the
    #                                                  can top IS the gear face 40.75)
    mp = motor_28byj("motor_pan")
    mp.apply_transform(R(-TAU / 4, (0, 0, 1)))       # offset +X -> -Y; ears -> X; wbox -> +Y
    mp.apply_translation((sx_, sy_ + P["motor_shaft_off"], zsh))
    add(mp, np.eye(4))
    # 32T drive gear, double-D bored onto the flats (fixed frame -- it spins with the
    # motor, not the platform). REAL generated involute teeth (tools/gears/gen_pan_spurs.py:
    # m0.8 / PA 20 / 32T+16T / CD 19.2, backlash 0.20 circular, probed 0.000 mm3 over a
    # coupled rotation sweep); pan_real_ok() falls back to gear_disc on any PARAMS
    # mismatch, PLACEHOLDER_GEARS=1 forces it (worm-pair convention).
    big_r = m_g * P["pan_gear_motor_t"] / 2                                # 12.8
    placeholder_pan = (os.environ.get("PLACEHOLDER_GEARS") == "1" or not pan_real_ok())
    if placeholder_pan:
        pg = gear_disc(big_r, P["pan_gear_motor_t"], gz1 - gz0, 2.0, axis="z")
    else:
        pg = load_gear_stl("pan_gear32_real.stl")    # axis Z, width 5, centered at origin
        # cosmetic mesh clocking (worm-wheel convention): both blanks generate
        # tooth-centered-on-+X and the gear sits at azimuth 180 (pan_shaft_azim), so the
        # measured zero-window center (meta gear32_mesh_deg, 5.625 = half a 32T pitch)
        # meshes it with the platform's integral 16T at pan=0. The platform (and pinion)
        # then pan by pan_deg, an external mesh counter-rotates the gear by half of that
        # (16T/32T, opposite sense -- sign probed in gen_pan_spurs' coupled sweep), all
        # mod one tooth pitch (11.25). The gear-teeth clocking is physically free; the
        # D-bore is cut AFTER, so its flats stay on the motor shaft flats (cf. the track
        # sprockets' disc-only clocking note).
        pg.apply_transform(
            R(((pan_gear_mesh_deg() - pan_deg / 2) % (360.0 / P["pan_gear_motor_t"]))
              * DEG, (0, 0, 1)))
    pg = sub(pg, dbore_neg(gz1 - gz0 + 1.2, axis="z"))
    _color(pg, "motor"); pg.metadata["name"] = "pan_gears"
    pg.apply_translation((sx_, sy_, (gz0 + gz1) / 2))
    add(pg, np.eye(4), "pan_gears.stl")

    # pan bearing: captured-BB lazy-Susan lower race + ball ring (fixed frame; platform is the
    # upper race). Balls carry the head weight on a wide circle -> no wobble, quiet, cheap.
    lower_race, balls, cage = build_pan_race()
    add(lower_race, np.eye(4), "pan_race.stl")
    add(balls, np.eye(4))
    add(cage, np.eye(4), "pan_cage.stl")             # BB spacer cage (drops in with the balls)
    # uplift retention: full-circle lip with six deck screw lobes
    add(build_pan_retainer(), np.eye(4), "pan_retainer.stl")

    # --- HEAD (tilt + pan): split into front bezel + back cover + rear service door ---
    for hp in build_head_parts():                    # bezel_L/R + back_L/R + door
        add(hp, M_head, f"{hp.metadata['name']}.stl")
    add(build_screen_tray(), M_head, "screen_tray.stl")  # bench-mounted module carrier
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

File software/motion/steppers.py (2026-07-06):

"""28BYJ-48 half-step driver for the desk-pi neck (pan + tilt).

Design constraints (see repo CLAUDE.md):
- Pan carries the Pi power cable as a SERVICE LOOP through the neck column.
  It must NEVER over-wind, so pan has a hard software clamp (default +/-88 deg,
  2 deg margin inside the +/-90 mechanical target). The clamp is enforced in
  move_to() and cannot be bypassed by relative moves.
- Tilt is a self-locking worm drive, +/-30 deg mechanical. Software clamp
  matches (default +/-30). The worm holds position de-energized, so we
  release the coils after every move (no idle current / heat).
- GPIO is via lgpio (python3-lgpio, in Raspberry Pi OS / Debian trixie repos).
  lgpio is imported LAZILY so this module imports and unit-tests on any
  machine (dry_run=True needs no GPIO at all).

Pins are parameterized with NO defaults: the robot is not built yet, nothing
is wired, and a wrong default silently energizing the wrong pins is worse
than an explicit error.

Usage (on the Pi, once wired):

    from steppers import PanStepper
    pan = PanStepper(pins=(17, 18, 27, 22))   # IN1..IN4 on the ULN2003
    pan.move_to(45.0)                          # degrees, clamped to +/-88
    pan.release()

Dry-run (any machine):

    pan = PanStepper(pins=(1, 2, 3, 4), dry_run=True)
    pan.move_to(120)      # -> moves to +88, returns 88.0
"""

import time

# 28BYJ-48 half-step sequence, applied to (IN1, IN2, IN3, IN4) on the ULN2003.
# 8 half-steps per electrical cycle; going forward = walking this list in order.
HALF_STEP_SEQUENCE = (
    (1, 0, 0, 0),
    (1, 1, 0, 0),
    (0, 1, 0, 0),
    (0, 1, 1, 0),
    (0, 0, 1, 0),
    (0, 0, 1, 1),
    (0, 0, 0, 1),
    (1, 0, 0, 1),
)

# Nominal 28BYJ-48: 32 steps/rev rotor, ~1:64 gearbox, half-stepping doubles it.
# The true ratio is 63.68395:1 (4075.77 half-steps/rev); 4096 is the usual
# nominal figure and fine for a face robot. Override per-instance if the
# accumulated error ever matters.
HALF_STEPS_PER_REV = 4096

# Datasheet max response frequency ~ 1000 pps at 5 V. 1.2 ms/half-step (~830 pps)
# is a safe default with load.
DEFAULT_STEP_DELAY_S = 0.0012


class LimitedStepper:
    """A 28BYJ-48 on a ULN2003 with a hard software travel clamp.

    Angle convention: 0.0 deg is the pose at power-on (the caller is
    responsible for physically homing/centering before construction, or for
    calling `zero_here()` after a manual home). Positive = forward walk of
    HALF_STEP_SEQUENCE; flip `invert=True` if the mechanism runs backwards.
    """

    def __init__(
        self,
        pins,
        limit_deg,
        steps_per_rev=HALF_STEPS_PER_REV,
        gear_ratio=1.0,
        step_delay_s=DEFAULT_STEP_DELAY_S,
        invert=False,
        dry_run=False,
    ):
        """
        pins:          (IN1, IN2, IN3, IN4) BCM GPIO numbers. Required, no default.
        limit_deg:     symmetric clamp; the axis will never be commanded past
                       +/-limit_deg from zero. Required.
        steps_per_rev: half-steps per revolution of the MOTOR OUTPUT shaft.
        gear_ratio:    extra reduction between motor shaft and the axis
                       (e.g. the 12T worm wheel on tilt). axis_deg =
                       shaft_deg / gear_ratio.
        step_delay_s:  seconds between half-steps.
        invert:        reverse the electrical direction for positive angles.
        dry_run:       no GPIO; pin writes are recorded in self.trace.
        """
        pins = tuple(pins)
        if len(pins) != 4:
            raise ValueError("pins must be exactly 4 GPIO numbers (IN1..IN4)")
        if len(set(pins)) != 4:
            raise ValueError("pins must be distinct")
        if limit_deg <= 0:
            raise ValueError("limit_deg must be positive")

        self.pins = pins
        self.limit_deg = float(limit_deg)
        self.steps_per_rev = int(steps_per_rev)
        self.gear_ratio = float(gear_ratio)
        self.step_delay_s = float(step_delay_s)
        self.invert = bool(invert)
        self.dry_run = bool(dry_run)

        # Position in half-steps of the AXIS (post-gearbox), 0 = home.
        self._pos_steps = 0
        # Index into HALF_STEP_SEQUENCE for the coil pattern.
        self._seq_idx = 0

        self.trace = []  # dry-run: list of (IN1, IN2, IN3, IN4) tuples written
        self._gpio = None
        self._gpio_handle = None
        if not self.dry_run:
            self._init_gpio()

    # ---------------------------------------------------------------- GPIO

    def _init_gpio(self):
        import lgpio  # lazy: only touched on real hardware

        self._gpio = lgpio
        self._gpio_handle = lgpio.gpiochip_open(0)
        for p in self.pins:
            lgpio.gpio_claim_output(self._gpio_handle, p, 0)

    def _write_pattern(self, pattern):
        if self.dry_run:
            self.trace.append(tuple(pattern))
            return
        for pin, level in zip(self.pins, pattern):
            self._gpio.gpio_write(self._gpio_handle, pin, level)

    def release(self):
        """De-energize all coils (0000). Always safe; on tilt the worm holds."""
        self._write_pattern((0, 0, 0, 0))

    def close(self):
        """Release coils and free the GPIO chip handle."""
        self.release()
        if self._gpio_handle is not None:
            self._gpio.gpiochip_close(self._gpio_handle)
            self._gpio_handle = None

    # ------------------------------------------------------------ geometry

    @property
    def steps_per_axis_rev(self):
        return self.steps_per_rev * self.gear_ratio

    def angle_to_steps(self, deg):
        return int(round(deg / 360.0 * self.steps_per_axis_rev))

    def steps_to_angle(self, steps):
        return steps * 360.0 / self.steps_per_axis_rev

    @property
    def position_deg(self):
        return self.steps_to_angle(self._pos_steps)

    def clamp(self, deg):
        """The hard limit. Every commanded target passes through here."""
        return max(-self.limit_deg, min(self.limit_deg, float(deg)))

    def zero_here(self):
        """Declare the current physical pose to be 0 deg (after manual homing)."""
        self._pos_steps = 0

    # -------------------------------------------------------------- motion

    def _step_once(self, direction):
        """One half-step. direction: +1 forward, -1 backward (axis frame)."""
        electrical = -direction if self.invert else direction
        self._seq_idx = (self._seq_idx + electrical) % len(HALF_STEP_SEQUENCE)
        self._write_pattern(HALF_STEP_SEQUENCE[self._seq_idx])
        self._pos_steps += direction

    def move_to(self, deg, hold=False):
        """Move to an absolute angle. Target is clamped to +/-limit_deg.
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

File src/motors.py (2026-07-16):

"""Bought-motor placeholder meshes: TT gearmotor, 28BYJ-48 stepper.

Split out of the original monolithic build.py (2026-07-10); see
build.py for the assembly entry point and the overall design notes.
"""
import numpy as np
from trimesh.transformations import rotation_matrix as R
from params import P, TAU
from geo import _color, box, cyl, sub, uni


def motor_tt(name):
    """TT gearmotor, measured (reference/tt-motor-1079893/NOTES.md, STEP B-rep). Local frame:
    OUTPUT SHAFT AXIS = the X axis (double-D exits +X); the 64.5 body runs along Y, gearbox
    front face (+tab) toward -Y, can toward +Y. Gearbox rect 36.80 x 22.40 x 18.64 (18.64 along
    the shaft), Ø22.4 collar (flat on the shaft side), can Ø20 (14.99 AF), Ø9.9 x 2.2 end boss,
    shaft Ø5.40 / 3.70 flats, 8.8 proud; 2x Ø3.0 mount holes 17.5 c-c, Ø2.8 tab hole, Ø4 nub."""
    gl, gw, gh = P["tt_gearbox"]                       # 36.80, 22.40, 18.64
    hx = gh / 2                                        # 9.32: gearbox face at local x=+9.32
    rect = box(gh, gl, gw); rect.apply_translation((0, 6.9, 0))            # y -11.5..25.3
    collar = cyl(gw / 2, 11.3, axis="y"); collar.apply_translation((0, 30.95, 0))
    cflat = box(4, 12.5, gw + 2); cflat.apply_translation((8.07 + 2, 30.95, 0))
    collar = sub(collar, cflat)                        # collar flat on the shaft side (z=-8.07 ref)
    can = cyl(P["tt_motor_d"] / 2, 13.5, axis="y"); can.apply_translation((0, 43.35, 0))
    for xc in (6.87 + 2, -(8.12 + 2)):                 # asymmetric 14.99 across-flats
        f = box(4, 15, P["tt_motor_d"] + 2); f.apply_translation((xc, 43.35, 0))
        can = sub(can, f)
    boss = cyl(4.95, 2.2, axis="y"); boss.apply_translation((0, 51.2, 0))
    stub = cyl(1.0, 0.7, axis="y"); stub.apply_translation((0, 52.65, 0))
    tab = box(3.0, 5.0, 5.0); tab.apply_translation((0, -14.0, 0))         # front tab, in -Y
    shaft = cyl(P["tt_shaft_d"] / 2, 8.8, axis="x"); shaft.apply_translation((hx + 4.4, 0, 0))
    for sz in (-1, 1):                                 # 3.70 across-flats over the outer 8.0
        f = box(8.2, 8, 3.0); f.apply_translation((hx + 0.8 + 4.1, 0, sz * (1.85 + 1.5)))
        shaft = sub(shaft, f)
    sboss = cyl(3.6, 0.5, axis="x"); sboss.apply_translation((hx + 0.25, 0, 0))
    nub = cyl(2.0, 2.0, axis="x"); nub.apply_translation((hx + 1.0, 11.0, 0))
    m = uni([rect, collar, can, boss, stub, tab, shaft, sboss, nub])
    for dz in (-8.75, 8.75):                           # 2x Ø3.0 mount through-holes, 17.5 c-c
        h = cyl(1.5, gh + 4, axis="x"); h.apply_translation((0, 20.3, dz))
        m = sub(m, h)
    th = cyl(1.4, 5, axis="x"); th.apply_translation((0, -14.0, 0))
    m = sub(m, th)                                     # Ø2.8 front tab hole
    _color(m, "motor"); m.metadata["name"] = name
    return m


def motor_28byj(name):
    """28BYJ-48 stepper, dimensionally correct: can + offset double-D shaft + two ears
    (holes on a can diameter) + wiring box. Shaft along +Z, shaft base at z=top.

    The output shaft is offset motor_shaft_off in +X; the two ear holes lie on the Y axis
    (perpendicular to the offset), 35 mm apart, centered on the CAN axis -> to land the shaft
    on a target axis you position the CAN, not the ears (see build()).

    2026-07-16 (user: "motors mounted wrongly to the gears"): the old placeholder stacked
    a phantom 9 mm "gearbox" tier between the can face and the shaft (motor_gear_h) --
    fiction; the real 28BYJ-48 gearbox lives INSIDE the 18.8 can and the shaft protrudes
    straight from the top plate (~28.6 total, confirmed by the reference mesh + datasheet).
    Every gear had been positioned to the phantom shaft plane, so the real motor's shaft
    could not reach it. The shaft-base planes (and every gear keyed to them) stayed put;
    the CANS moved 9 mm toward their gears via the derived can-bottom formulas.
    """
    r = P["motor_can_d"] / 2
    off = P["motor_shaft_off"]
    can = cyl(r, P["motor_body_h"]); can.apply_translation((0, 0, P["motor_body_h"] / 2))
    top = P["motor_body_h"]
    boss = cyl(P["motor_boss_d"] / 2, 1.45); boss.apply_translation((off, 0, top + 0.72))

    # double-D output shaft: round Ø motor_shaft_d, flats motor_shaft_flat apart over top 6 mm
    sl, fl = P["motor_shaft_len"], P["motor_flat_len"]
    shaft = cyl(P["motor_shaft_d"] / 2, sl); shaft.apply_translation((off, 0, top + sl / 2))
    for sy in (-1, 1):
        cutter = box(P["motor_shaft_d"] + 2, P["motor_shaft_d"], fl + 0.5)
        cutter.apply_translation((off, sy * (P["motor_shaft_flat"] / 2 + P["motor_shaft_d"] / 2),
                                  top + sl - fl / 2))
        shaft = sub(shaft, cutter)
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

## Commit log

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2026-07-05 Fix tilt-axle Z misalignment + reshape from multi-agent review
    - CRITICAL: neck clevis was 46mm too high (built at absolute zt then re-lifted by
    base_h); unify to world Z so the clevis actually mates the tilt axle. Seat pan_platform
    at the base top instead of the floor.
    - base -> truncated cone (Ø208 bottom / Ø156 top), grounds the head + tip margin
    - neck column rounded + squarer (48x46, r10), reads as a neck not a plank
    - head face lean 11->8deg, flatter crown, smaller camera nub with a lens hole
    - Pi 5 moved into the head behind the tilt axis (DSI/CSI stay in head, doubles as
    tilt counterweight) -- resolves the pan-motor/Pi collision in the base
    - motors shaped as 28BYJ-48 (chosen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
    [base.stl, head_shell.stl, neck_clevis.stl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]
2026-07-05 Split head for printing + cable routing + hollow base
    - head split into head_bezel (front, retains screen via a lip) + head_back (rear cover,
    hubs, Pi bay, cable port); screen drops into a stepped aperture and is trapped
    - rear service opening shrunk to a cable port (access is by removing the bezel)
    - verified no neck/head collision through tilt +-30 after the Z fix
    - hollow tilt axle (tube) for on-axis cable pass; vertical cable channel down the neck;
    base hollowed into a real motor cavity + off-axis cable pass to match the neck
    All 6 printed parts watertight.
    [base.stl, head_back.stl, head_bezel.stl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]
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2026-07-05 Fix screen orientation: TAU was pi not 2pi (footgun)
    - TAU=pi made R(TAU/2)=90deg; screen_flip then tipped the LCD 90deg onto its back
    while the aperture stayed vertical -> 'screen position wrong'. Set TAU=2pi and fix
    call sites: cyl 90deg rotations (TAU/4), base bolt circle (was double), tilt motor
    (was -45 now -90), vents (now full circle). Screen flip is now a 180deg yaw.
    - pull screen flush with the bezel (cantilever 39->31)
    [base.stl, head_back.stl, head_bezel.stl]
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2026-07-05 Tank-tread chassis: two side track pods + central body replace the cone base
    - build_base is now a rounded chassis body (pan motor + driver + wiring, pan-mount on top)
    - build_tracks: two stadium belt loops (drive+idler hub caps) flanking the body, belt to ground
    - neck/pan/head unchanged (base_h=52 kept as the pan-mount plane) -> turret on a tank
    - STLs: chassis + track_L + track_R (routed to stl/base/)
    [base.stl, chassis.stl, track_L.stl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]
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2026-07-06 Finalize pan/tilt/track drivetrain from mechanism research
    Implements the mechanism decisions from a 6-agent research pass into
    src/build.py (was placeholders throughout):
    - 28BYJ-48 placeholder made dimensionally correct (Ø28.25 can, 7.875mm
    offset shaft, Ø4.93 double-D with 3mm flats). New dbore_neg/dbore_hub
    D-socket coupling helpers.
    - Pan: direct D-bore hub couples the offset shaft on-axis; new
    build_pan_race() adds a captured-BB lazy-Susan race (pan_race + balls,
    Ø80 circle) replacing the fake seat. Cables = service loop (±90°).
    - Tilt: self-locking single-start worm drive (gear_disc worm_wheel +
    worm), right-angle motor layout. Axle changed M6 -> Ø5 hollow on
    695-2R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
    [cam_cover.stl, chassis.stl, head_back.stl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]
2026-07-06 Fix campaign: 30 verified defects + design changes, independently verified
    Five fix stages + two independent verification gates (docs/FIXES.md is the
    full ledger with probe numbers per item):
    - Stage 1 (prev. session): chassis deck, pan BB race stack, uplift clips,
    D-bore over flats only, motor pedestal.
    - Stage 2: tilt drive functional (open bearing seats, keyed 12T wheel with
    spacers, driveable worm, motor pocket at the can axis, axle clamp bosses,
    full +-30 sweep).
    - Stage 3a: screen+Pi combined module (official Pins-Out mesh, glass-plane
    anchored pose), rear-standoff retention, official CM3 camera aperture
    (6.3/8.0 csk), Pi I/O slot re-aim, 8 bezel posts.
    - Stage 3b: tracks fr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
    [DC_Motor_20mm.STEP, DC_Motor_20mm.STL, MR4_BodyInterface.stl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]
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2026-07-06 Styling 6/6: placeholder gripper arms + interference fixes
    - arm_L/R: shoulder disc on the side rail, upper arm + forearm limbs, cosmetic
    joint discs, C-claw opening forward; static tucked pose per front.jpg.
    Actuation/joints/mount decision deferred to an arm mechanism pass
    - shoulder discs h10 so they LAND on the rail face (were buried 1 mm, 254 mm3)
    - chassis floor slot for the HC-SR04 body (board reached z 9.05 vs floor 12)
    - probe: all new styling parts x all parts, 0.000 mm3 overlaps (surface contacts only)
    [build.py]
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2026-07-06 Styling: chassis rear panel + cylinder pod
    - trim_rear: orange frame panel on the rear wall, wall shows through the
    44x14 opening as the hatch; USB-C slot stays clear below
    - sensor_rear: silver Ø14 cylinder pod (speaker/buzzer placeholder), lands
    on the wall, image-right per the reference back view
    [build.py]
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2026-07-06 Head drop: whole head+tilt stack 25mm lower (design-ref neck gap)
    - body_z_bot/top, tilt_axis_z, screen_cz, cam_lens_z, neck_top_z and all
    styling z-params shifted -25 together, so the verified relative drivetrain
    geometry (worm mesh, cheeks, slot, camera bay) is unchanged
    - clevis root block, cheek anchors, chin notch + hatch-frame notch re-keyed
    to tilt_axis_z (they were literals at the old axle height and collided)
    - pose-grid interference sweep (pan x tilt corners, 9 poses): 0 unexpected
    hits; intended couplings (worm mesh, ball groove, D-hub) whitelisted
    [build.py]
2026-07-06 Base resize: chassis_w 120->140, base_h 52->66 (design-ref proportions)
    - track outer faces at +-102 ~= head half-width 102.5: head overhang GONE
    (the long-pending gauge widening); claws keep 4 mm to the pods, which is
    why 140 and not 148
    - taller chassis: neck gap 22 (was 36 post-drop, 61 originally); fascia
    rides up (grille cz 46, ultrasonics 26, lamps +-54), HC-SR04 floor
    recess removed (board clears the floor now)
    - deck pocket + corner relief literals derived from chassis_w
    - probes: full fixed-pair matrix at neutral + 9-pose pan/tilt sweep ->
    only the intended ball-groove contact (0.03 mm3)
    [build.py]
2026-07-06 Tracks 1.6x wider (28 -> 56 -> 44.8 per user) + raised arm pose
    - link knuckle comb now width-derived (outer set runs to tw/2; sprocket
    channel +-4.9 and inner set fixed), sprocket band pinned to 8 wide
    - idler + road wheels 30 wide; idler grows OUTBOARD only (symmetric growth
    swallowed the chassis tension plate, 830 mm3)
    - arms: RAISED pose per front-2.jpg (the wide pods sit under the old tucked
    claw sweep at pan ~20 + tilt down); shoulder standoff tube bridges the
    rail face to the arm plane at x 127; claw C opens upward
    - full probe: fixed-pair matrix + 14-pose pan/tilt sweep (incl pan 20/45)
    -> 0 unexpected hits
    [build.py]
2026-07-06 Verification gate: src/assembly_check.py + make check / check-sweep
    - pairwise manifold interference over all GLB nodes (AABB prefilter,
    0.01 mm3 threshold, screen_ref excluded, throwing booleans = violation
    per the FIXES.md stage-4 lesson, not swallowed)
    - --sweep: 14-pose pan x tilt grid via PAN/TILT/OUT into build.py
    - whitelist: the 5 intended couplings (worm mesh, wheel spacer, BB grooves
    x2, pan D-hub); verified non-vacuous (measures real coupling volumes)
    - both targets pass on current geometry (630 pairs ~1.5s; sweep ~45s)
    [assembly_check.py]
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2026-07-06 Real worm drive geometry: involute 12T wheel + single-start worm
    - first-principles numpy involute + manifold helical extrude/sweep in a
    uv py3.10 venv (bd_warehouse has no worm generator; no OpenSCAD here)
    - CD = 11.900 (was 11.5: the Ø7 worm core forces it; worm_cd() change
    pending integration), lead angle 8.085 deg RH -- <5 impossible at m1.25;
    still self-locks (needs mu>0.129, dry PLA 0.3-0.4; grease caveat in doc)
    - 25 deg PA (12T undercuts at 20), wheel helix matched, backlash 0.25
    - verified: watertight both, assembled-phase intersection 0.000 mm3 with
    first flank contact at CD-0.10 (designed backlash), wrong-hand wheel
    cannot mesh; section renders checked
    - docs/WORM.md: d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
    [tilt_worm_real.stl, worm_wheel_real.stl]
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2026-07-06 10 audit fixes: printability (7) + cable route (3)
    Printability: camera_pod 40deg flare + h20 (wall 0.05->1.85 @0.3mm);
    fascia backing webs (7 bodies -> 1); gear_disc teeth sunk 1.0 into the
    root (sprockets 4 bodies, worm_wheel 1); road wheel Ø4.2 bores; idler
    tension arm extended to fuse its plate (chassis 3 bodies -> 1, radial
    10.8 < 15.7); hex grille rotated to flat-top (web 0.736 -> 1.200,
    self-supporting roofs); LED bases -> 1.2 (dot proud heights kept).
    Cable: deck pass re-based z 29..53 AND moved after the pedestal union
    (doc missed extrude_polygon's z=0 base -- cut was at 40..62); Ø5 conduit
    sweep min clearance 2.52mm; neck side exit window (-12,-26,122) probed
    open into the left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
    [build.py]
2026-07-06 Real fixings on every styling part + arm shoulder interface + CD 11.9
    - rails: 3x Ø3 pins/side into blind wall sockets (1.5 skin); glue
    - arm interface (under the rails, arms currently off): 2x M3 captive-nut
    pockets/side flush in the 4mm wall (interior pads impossible: display
    slide-in needs its 2.0 clearance), horizontal pair y +-8 z 132, M3x10
    ONLY (x12 tip would hit the display), Ø6.2 wire pass at z 130
    - hatch frame 4 pins (+-72, 196/106); fascia 4 pins under the backing
    webs; rear panel 3 pins; camera_pod 2x Ø2 pins above the glass line;
    antenna Ø6 spigot into the top wall; LED/lamp wire passes (led_front's
    angled -- straight dead-ends in the floor band); sensor_rear Ø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
    [build.py]
2026-07-06 Head deepened to contain the tilt stepper (user todo)
    - body_back_y -31 -> -70 (depth 62 -> 101); motor can rear at y -64.3,
    1.7mm static clearance at neutral, 2.77mm worst across the tilt sweep
    - motor bay slot x +-33, y -78..21, z 78..168 (probe-derived from the
    swept pan-frame group); old rear cable port deleted -- the bay is the
    cable route; louvres reshaped 3x 70-wide z 171..189
    - screen standoffs grew to 88.5 (needs a ~90mm reach driver -- assembly
    audit item); 4-thick gusset webs tie each standoff pair, verified 20mm
    behind the real stack bbox, channels stay open
    - sweep margin 4.71mm over the platform at +30; cable exit window open
    at all tilts; make check + check-sweep P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
    [build.py]
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2026-07-07 DFA audit: verified 18-step assembly order + driver-channel fix
    - verdict: complete install order EXISTS; docs/ASSEMBLY.md order section
    rewritten as a verified numbered sequence w/ tool callouts
    - fix: screen-standoff driver channels Ø6.5->7.0 (probed open Ø6.4; a csk
    M3 head could not enter, pan head had 0.45mm; now ~0.75mm + hex bit
    room, 1.0 wall left in the Ø9 standoff)
    - proven order constraints: rails before links, join+TT screws before
    ULN#1, neck-platform is a bench sub-assembly, wheel grub on the bench,
    BBs before platform, ballast before belly, screen before hatch frame
    - nasty-but-possible documented: 95mm slim pan-head driver for the
    standoffs, stubby Ø3 bit for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
    [build.py]
2026-07-07 Real worm gears integrated (placeholders retired)
    - load_gear_stl(): committed real-tooth STLs replace gear_disc/worm in
    build(); hub/tubes/bore/grub ops unchanged; PLACEHOLDER_GEARS=1 fallback
    - phase clocking (24.5 - tilt) mod 30 so teeth mesh at any pose; pair
    intersection 0.0 mm3 at preview (whitelist headroom)
    - D-bore wall 0.915 round / 1.88 flat, 1440/1440 core samples solid;
    grub lands on the plain hub; bench-cartridge DFA note added
    - stl/ tree refreshed: +belly_plate, pod rails, track_wheels, head_door,
    tilt_worm, worm_wheel; all gates + EXPORT pass
    - CLAUDE.md status synced
    [belly_plate.stl, cam_cover.stl, chassis.stl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]
2026-07-07 Track-link test plate script + stale sprocket docstring fix
    - tools/test_plate_links.py -> exports/test_plate_links.3mf (regenerable,
    gitignored): 5 links grouser-UP (grouser-down is unprintable: 90deg web
    overhang; the inner-face draft chamfers ramp the 4mm bridge), sprocket
    gear-face down, Ø1.9/2.0/2.1 pin gauge, pod-rail nut/dowel coupon w/
    exact rail dims; PETG A1 profile, support-free (audited), bed-checked
    - sprocket docstring synced to derived values (was pod 78 / hub -19.7)
    [build.py]
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2026-07-08 Maintenance/DFA pass: service cartridges, master links, homing stops, 12V power tray
    Workflow-reviewed (5 lens agents + 2 adversarial critics) simplification of
    assembly, maintenance and extendibility; all changes gated by make check +
    the 14-pose check-sweep (both green) and reviewed in fresh renders.
    - tilt_carrier: tilt 28BYJ + worm become a rear-access cartridge. Ears bolt
    to the carrier on the bench; 4x M3x16 drive from the open rear bay into
    thread-form pilots; the worm extracts axially through the plate's grown
    O12.2 bore (worm-as-rack spins the free wheel). Kills the 2.1 mm ear reach
    and the head teardown for a motor swap.
    - Worm wheel D-keyed to a flatted O5 axle (hub ledge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
    [belly_plate.stl, chassis.stl, head_back.stl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]
2026-07-08 Two-agent review fixes (printability + mistakes) and the finnish-doors fit map port
    Printability agent (measured on the STLs):
    - sd_plug: body now overlaps the face plate 0.7 (was a 0.1 AIR GAP -- the part
    sliced as two loose bodies) and gets +0.4 clearance on the y-min face, whose
    mating slot surface is a 16 mm unsupported bridge in the face-down bezel.
    - tilt_carrier: the corner-clip cut severed the plate into 3 bodies (both lower
    bosses were floating islands). Replaced by a two-stage relief: full x-clip
    17..24.6 below z 126.5 where the cheek spans the whole carrier depth, plus a
    rear-wing thinning (y -50.55..-48.4) above; single watertight body verified.
    - master link: keeper pi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
    [chassis.stl, neck_clevis.stl, pan_platform.stl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]
2026-07-08 screen_tray: kill the 4 long blind LCD screws (user request)
    The screen+Pi module's retention was 4x M3 pan heads driven down 88.5 mm blind
    O7 channels from the outer back wall (nasty step #1 in both reviews, needed a
    ~95 mm slim driver and had 0.75 mm of head clearance). Root cause of the
    channels: the display's factory bosses open backward, a bezel-side boss punches
    the glass (stage 3a), and the deep head put the back wall 88.5 away.
    New: build_screen_tray(), a one-piece carrier (2 rails + spine).
    - BENCH: 4x M3x10 pan straight into the factory 126.2x65.65 bosses; the tray
    pillars are z-offset from the bore axes so the driver line is open. The
    module becomes a bench-testable unit (pow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
    [head_back.stl, screen_tray.stl]
2026-07-10 Viewer pose sliders, screwless rear pod door, RC-tank running gear
    - viewer: live Pan/Tilt sliders + sweep animation; build.py writes a per-model
    pose sidecar (assembly.pose.json) with baked angles + kinematic groups so the
    viewer re-poses the baked GLB by delta rotations
    - head_door: tool-free retention (top hooks + per-leg snap tongues, barbs click
    behind the wall band; pull the pod bottom to open) replacing 2x M3 csk; the
    door face is now the design-ref stepped backpack POD (tiers to 35 mm proud,
    hollow: drivetrain sweep cavity + neck stall corridor, probed to the 33.8 deg
    stalls with 1.85 mm worst clearance); rear_pack + floating tilt_shroud removed
    - tracks: raised tank loop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
    [chassis.stl, chassis_deck.stl, chassis_lower.stl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]
2026-07-10 Split build.py into per-subsystem modules
    Verbatim code motion out of the 3.4k-line monolith: params (PARAMS dict),
    geo (primitives/booleans/colors), gears, screen, motors, tracks, pan, neck,
    head, chassis, fitmap; build.py keeps only the assembly entry. Import graph
    is a DAG (params imports nothing local). Pre/post GLBs are identical per part
    (vertex/face counts + bounds), all gates re-run green. watch.py now watches
    the whole src/ module set. Scratch OUT= builds (_check.glb) skip the pose
    sidecar.
    [build.py, chassis.py, fitmap.py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]
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2026-07-10 Stretch the chassis to the RC-tank ref proportions
    chassis_l 156 -> 200, wheelbase 161.325 (solved: same 33 deg ramp / 147 deg
    wrap end geometry as before, loop closes at exactly 45 x 10), ground run
    +-72.5, 6 dished road wheels (pitch 21, outermost +-52.5 with 3.5 mm lateral
    gap to the raised discs). Everything downstream follows parameters: fascia +
    rear features ride fw, TT motors + mounts + tab pockets + idler arms ride
    ys = -wb/2. Hand-moved: rear deck-split bosses to the longer rear wall
    (+-34, -93), pod joins spread to +-40, side vents extended to +-48/64.
    make check + check-sweep + fits all green.
    [chassis_deck.stl, chassis_lower.stl, track_keeper_L.stl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]
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2026-07-10 head_back in four: flat panels + ceiling-free frames
    The L/R halves still printed open-front-down with the whole back wall as a
    supported ceiling. Each half is now a flat BACK PANEL (4mm wall slab with the
    door rebate/void, snap catch band, tray screw holes; prints lying flat, outer
    face up) + a WALL FRAME (side/top/bottom walls, pivot hubs, antenna bosses;
    prints front-down with no ceiling). 6x M3 axis-Y from the back join panel to
    frame rim tabs (side tabs inter()-clipped into the corner mass); frame halves
    keep the top-wall flange, panel halves the tongue/groove. The gusset webs in
    the old docs no longer existed in the geometry. All four watertight; gates +
    sweep + fit audit (49 expected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
    [head_back_frame_L.stl, head_back_frame_R.stl, head_back_panel_L.stl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]
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2026-07-10 Track-drive fix pass: wheel axles, idler 2nd bearing, real sprocket pockets
    - Road wheels were mounted to nothing: each pod rail grows a wheel beam
    (x 74..80.4, z 14..26, y +-58) with 6x M4x40 bolt-axles in captive-nut
    slide-up slots; head doubles as the outer hubcap, 1.0 running gap.
    - Idler ran 30 wide on a single 5-wide F688ZZ at one face (wobble hinge):
    flange recess now at BOTH faces, 2 bearings per idler (BUY 4).
    - Sprocket teeth were placeholder gear_disc trapezoids with ~0.36 radial
    pin engagement: real pin pockets now (12x r1.15 seats on the 19.32 pin
    circle, 0.63 bite, 2.05 mouth clears the O1.75 pin).
    - Doc rot: 36->45 links everywhere, BOM/assembly steps updated.
    Gates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
    [chassis.py, tracks.py]
2026-07-10 Toy-tank hull: deck overhangs both ends, cliff sensor in the front slope
    User round 2: upper deck +5 cm each side (top plate 300), lower tub +2 cm
    each side (chassis_l 240), end faces sloping 33.7 deg from horizontal like
    an RC-tank hull. The HC-SR04 sits flush in the front slope (normal = 33.7
    deg ahead of straight down), board behind the 5-thick skin in an underside
    pocket that opens over the tub for wiring. Re-homed: grille (cz 32, 60x26,
    US barrels inside its opening), fins/lamps/pins, hex field onto the slope,
    TT tab ribs at the old rear-wall station, rear deck screws to y -113.
    Also fixes two pre-existing loose-body bugs found probing: idler tension
    plate crown sliced into chassis_deck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
    [chassis.py, params.py]
2026-07-10 Rear cliff sensor + connectivity audit fixes
    - sensor_cliff_rear: the front slope's HC-SR04 construction mirrored onto
    the rear overhang (reversing cliff detection); rear pocket narrowed to
    x +-28 (deck-split bosses at +-34), rear hatch frame dropped + squashed
    to 72x18 cz 28.5 (the rear barrels sweep to ~z 39 past the wall plane).
    3x HC-SR04 total; inventory has none, BOM buy line added.
    - Connectivity audit (user todo): all 60 parts checked for loose internal
    bodies and assembly contact. Fixed: ant_bracket motor face plates were
    severed by their own O28.7 can-pass bores (bottom halves + lower ear
    pilots floated) -- plates deepened to 36 with a wiring-box notch in the
    rear l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
    [chassis.py, head.py, params.py]
2026-07-10 Rear obstacle sensor, twin grille trims, track stretched to the hull
    - sensor_us_rear: HC-SR04 board + barrels mirrored onto the rear wall, so
    the rear has TWO proximity sensors (obstacle + cliff) like the front;
    O16.6 barrel bores added, board seat whitelisted in the fit audit.
    USB-C entry + PD pilots moved x 0 -> -38 so the barrels own the center.
    - Trims: rear = twin of the front grille ring (squashed 72x18 hatch frame
    deleted); front fin/web stubs deleted (vestigial on the 28-tall band);
    fascia/rear pins re-clocked into the ring bands.
    - Track loop stretched for the toy-tank hull (user: too short from the
    side): 52 links, ground run +-90, wheelbase 196.326 (wb/2 - g held at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
    [chassis.py, fitmap.py, params.py]
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2026-07-10 Mid-drive tracks past the deck tips + centered ears
    User chose 'tracks 1 cm past the deck tips' (+-154): past the coaxial-TT
    limit, so the drive architecture changed. Both loop ends are now FREE
    IDLERS (O8 stubs pressed/tensioned in deck-overhang pylons at x 62..70;
    front pair carries tension slots + M3 set screws) and the DRIVE SPROCKET
    sits inside the loop ON THE GROUND RUN at spr_y -68, where the robot's
    weight presses the straight run into the pin pockets (rack-style 2-3 pin
    bite). TT motors stay direct-drive, dropped ~9 to the pin line; spr_y is
    the derived slot missing the ULN posts, pod-join nut band and vents (row
    re-clocked). 64 links, wheelbase 256.326, ends +-153.6. Wheel row is a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
    [assembly_check.py, build.py, chassis.py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]
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2026-07-11 M8 end bolt-axles + optional second drive station per side
    - End idlers had no axial retention on their plain O8 stubs (user: 'two
    wheels per side not connected'): each now rides an M8 bolt-axle, head
    = outboard hubcap, nut on the pylon's inboard face; the front nut
    clamps the tension slot (M3 set screws gone; rear sockets now O8.4
    through). BOM: 4x M8x60 + nuts.
    - Second drive station per side at spr_y2 +90 (user: two motors, second
    optional, fittings ready): full TT feature set mirrored (flipped
    gearbox trails rearward), sprocket 2 on the optional motor's shaft,
    drive2_L/R placeholders modeled. Road wheels 6->5 stations, second
    beam hub notch, y80 vent re-clocked, ULN2 move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
    [build.py, chassis.py, params.py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]
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2026-07-11 Bambu export: current running gear from split STLs, 20 plates
    drivegear_units now splits the exported track_wheels STLs instead of
    duplicating recipes (which had drifted: roadwheel_count param gone, end
    idlers missing, dual sprockets unknown). Output exports/bambu.3mf:
    20 category plates, 177 printed bodies (4 sprockets incl. the optional-
    motor pair, 4 end idlers, 10 road wheels, 128 links). Stale pre-split
    STLs removed.
    [ant_bracket.stl, belly_plate.stl, chassis_deck_center.stl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]
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2026-07-11 Granular scene nodes: select every link/wheel/fastener in the viewer
    Multi-body drive parts emit dotted child nodes (track_L.link_00,
    drivewheels_R.sprocket_front, axle_hw_L.end_bolt_rear, keeper bars):
    224 scene parts. Gates re-group by the pre-dot prefix (still 67 nodes,
    whitelists untouched, identical pair results); print export gets one
    multi-body ghost per parent (scene=False). Viewer nests children as a
    collapsed 3rd tree level and resolves fit-map pair names by prefix.
    [assembly_check.py, build.py, fitmap.py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]
2026-07-11 Viewer: wider panel for the 3-level tree; solid + fit-map-off defaults
    336px HUD (names no longer truncate with the sub2 level), parts list
    44vh, transparency slider defaults to 0% and the fit map checkbox to
    off per user. shoot.py TRANS unset now renders solid too.
    [tilt_worm.stl, worm_wheel.stl]
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
